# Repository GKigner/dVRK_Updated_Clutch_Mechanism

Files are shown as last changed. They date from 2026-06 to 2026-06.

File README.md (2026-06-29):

Last updated 6/28/2026.
This is the repo for setting up and running the updated clutch mechanism for the dVRK. Both "quickstart" and detailed instructions can be found in the instructions directory.

Thank you to Brendan Burkhart, Arko Chatterjee, and Professor Peter Kazanzides. Without them, this project would not be finished.

If you have any questions, please email gkigner1@jh.edu

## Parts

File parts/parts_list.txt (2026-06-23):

Spring (2): https://www.thespringstore.com/pc010-156-14000-mw-0670-c-n-in.html
Camera (2): https://www.amazon.com/Arducam-Monochrome-Distortion-Microphones-Compatible/dp/B096M5DKY6?th=1
USB-A Extendors (2): https://www.amazon.com/Extension-Cable%EF%BC%8C20FT-Extender-Keyboard-Playstation/dp/B0836S4249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
850nm IR LEDs: https://www.amazon.com/Infrared-Lighting-Electronics-Components-Emitting/dp/B01BVGIZIU?th=1
Batteries: https://www.amazon.com/YKM-LR41-Batteries-AG3-Thermometer/dp/B0CFVSW7W1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 (should work)
Filters (2): https://www.thorlabs.com/item/fbh850-40

3D printed parts (found in this directory)

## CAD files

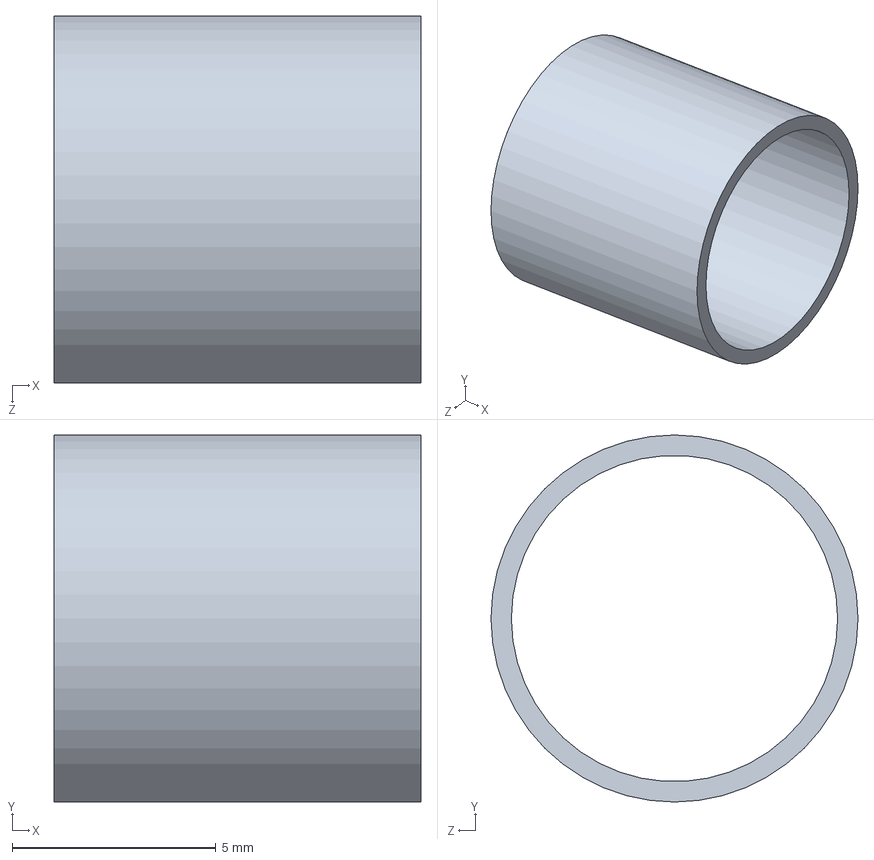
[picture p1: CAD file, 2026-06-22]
parts/led_legs_molder.SLDPRT
9.00 x 9.00 x 9.00 mm

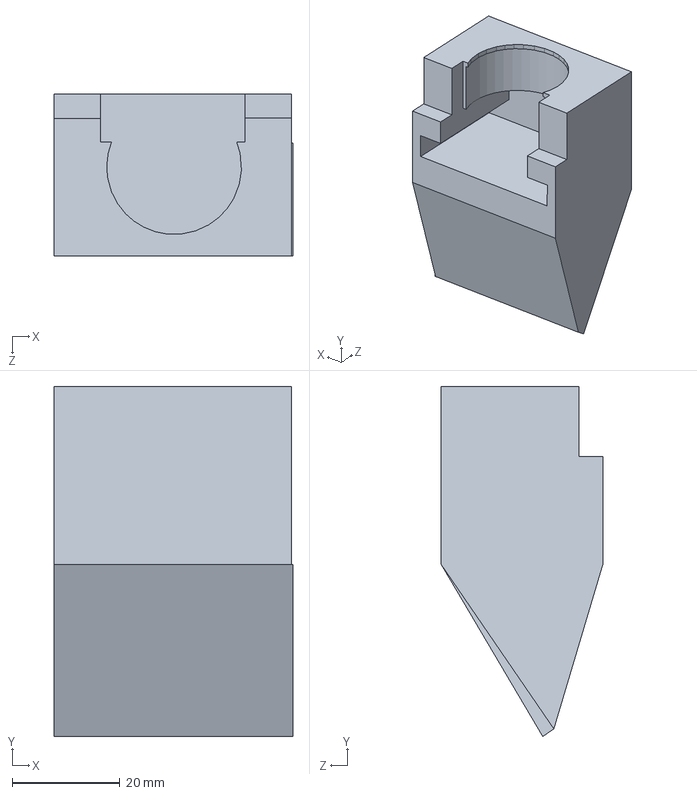
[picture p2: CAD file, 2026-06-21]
parts/Camera_Mount.SLDPRT
44.3 x 64.9 x 30.0 mm

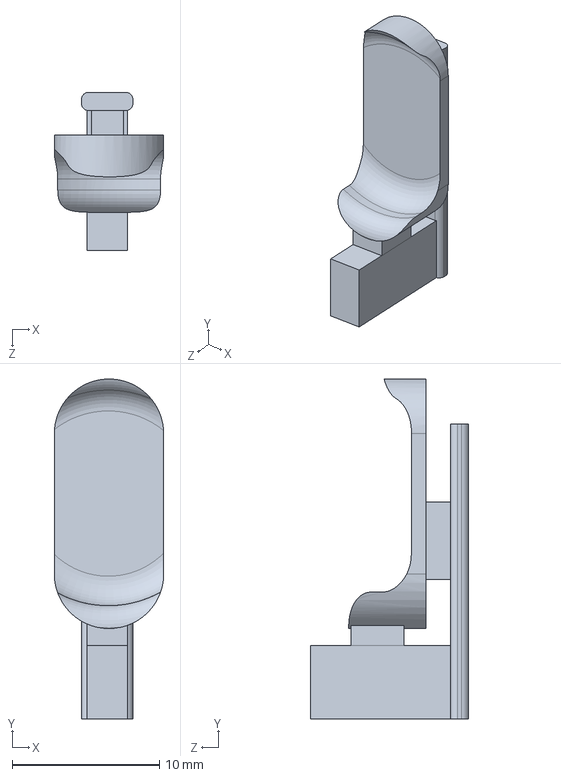
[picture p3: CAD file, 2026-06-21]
parts/Slide_Switch.SLDPRT
7.42 x 23.1 x 10.8 mm

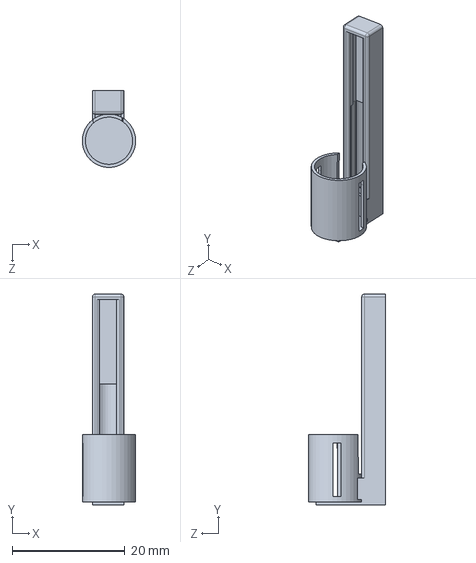
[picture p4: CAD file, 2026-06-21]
parts/Housing.SLDPRT
9.48 x 37.5 x 13.6 mm

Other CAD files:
parts/Camera_Mount.STL
parts/Housing.STL
parts/Slide_Switch.STL
parts/led_legs_molder.STL

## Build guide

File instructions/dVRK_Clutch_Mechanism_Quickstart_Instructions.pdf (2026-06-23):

## dVRK Clutch Mechanism Quickstart

Do everything once per arm. For a more detailed guide, see the detailed instructions.

Conventions. Most scripts have a side = RIGHT/LEFT hyperparameter near the top - set it before every run. Many also have a True/False toggle (collect data, overwrite, RESET LABELS) for switching between modes. Confirm the camera index in each script matches the camera for the current side (v4l2-ctl --list-devices).

### 1 Camera Calibration

Directory: camera calibration/

1. Run camera test.py. Twist the lens to maximize focus.
2. Run take pictures for calibration.py. Press SPACE to capture, Q to quit. Take at least 50 images of the ChArUco target from varied angles, as close as possible while keeping it in frame.
3. Optional sanity check: run calibrate camera debug.py to verify corner detection.
4. Set side in calibrate camera.py. Run it. Intrinsics are written to four locations automatically.

### 2 Hand-Eye Calibration

Directory: hand eye calibration/

1. Insert camera into camera mount.STL (JST connectors up). Tape mount to arm with bottom edge ∼16 cm from MTM start, perpendicular to the arm. Tape down JST wires.
2. Tape asymmetric-circles target on MTM near its stationary point. Use a phone flashlight below the target to compensate for the IR filter.
3. Verify camera intrinsics.json is for the correct side.
4. Set side and collect data = True in mtm registration.py. Confirm MTM is on. Run.
5. Capture 10–15 poses (head-on, twisted L/R, varied) with ENTER. ESC to finish.
6. Inspect output: blue (Z) axis along MTM, point at the stationary point. If not, repeat. Expect several iterations.
7. Once good, set collect data = False to review or run mtm registration debug.py to debug.

### 3 LED Data Collection

Directory: hand eye calibration/

1. Assemble clutch: spring in bottom compartment, batteries (+ up), slide switch, LEDs on opposite sides. See video for how to set this up by clicking on the video walkthrough. (https://livejohnshopkins-my.sharepoint.com/:v:/g/personal/gkigner1_jh_edu/IQDOQr961CYSQqJtsMTVazflAf39CZjWFqAWa4xZ-28Sw3I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)
2. Attach clutch to MTM.
3. Set side in led data collection.py. Run.
4. Manipulate the MTM through varied poses, keeping the clutch engaged the entire time. ESC when done.

### 4 LED Triangulation and ROI Calibration

Directory: led calibration/

1. Confirm camera intrinsics.json and link3 wrt camera.txt are present (written by earlier steps).
2. Set side in label leds.py. Run.
3. For each frame: left-click LEFT LED, then RIGHT LED (order matters). Right-click to undo. x to skip, q to quit.
4. Validate: set side in live roi view.py and run. ESC quits, r toggles ROI. Verify ROI tracks the LEDs.

### 5 Live Operation

Directory: live scripts/

1. Verify the camera index in each clutch signal *.py matches the correct device for that arm.
2. slide the IR filter in front of the camera on the camera mount
3. Run clutch signal left.py and/or clutch signal right.py (each is hardcoded to its arm; no side flag).
4. Subscribe downstream code to led left on and led right on (std msgs/Bool, ∼100 Hz).

### 6 Recalibrating LEDs Only

Directory: recalibrate leds/
Same scripts as before, but with side-tagged files (led data {side}/, led calibration {side}.json, common {side}.py). Each script has its own side hyperparameter. label leds.py writes to both recalibrate leds/ and live scripts/
- the second write is what makes the new calibration take effect. To redo hand-eye, restart the full setup.

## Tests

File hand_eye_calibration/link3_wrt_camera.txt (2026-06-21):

Example result (this text should be removed when you do everything):
7.005272617086488740e-02 9.975414640338271521e-01 -1.908687842116614779e-03 3.307541904463979186e-03
-3.160690696436230240e-01 2.401079258139704117e-02 9.484322986139954725e-01 -1.255507186751763926e-01
9.461463728042535104e-01 -6.583699091591255215e-02 3.169740239459591935e-01 2.546209383031390328e-01
0.000000000000000000e+00 0.000000000000000000e+00 0.000000000000000000e+00 1.000000000000000000e+00

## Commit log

2026-06-21 code for everything
    [Camera_Mount.SLDPRT, Camera_Mount.STL, Housing.SLDPRT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]
2026-06-22 ready for testing, instructions are good, just need to add in some more images and details, and then test clutch fully
    [led_legs_molder.SLDPRT, led_legs_molder.STL]
